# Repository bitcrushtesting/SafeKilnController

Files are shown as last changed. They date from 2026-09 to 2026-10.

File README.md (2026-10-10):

<!--
SPDX-FileCopyrightText: 2026 Bitcrush Testing
SPDX-License-Identifier: GPL-3.0-or-later
-->

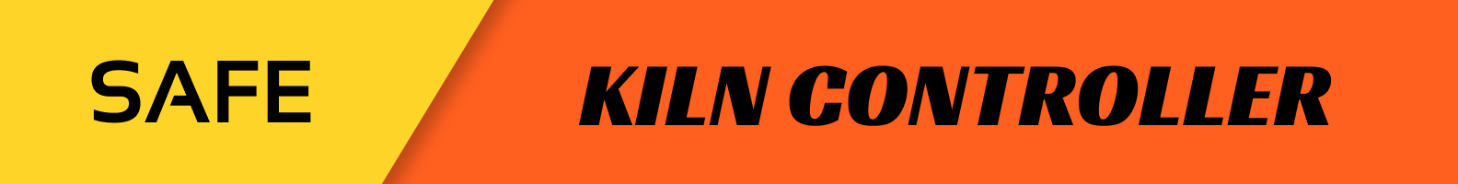
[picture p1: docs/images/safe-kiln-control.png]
Safe Kiln Controller


# Safe Kiln Controller








An open-source PID controller for electric ceramic and glass kilns, built on the
**ESP32-S3** with **ESP-IDF**.

- **Simple local display**: a 128×64 OLED showing current and target temperature at a glance, plus state, segment progress and rate of rise.
- **Web interface**: served by the device itself. Live dashboard, charts of the logged data, power and energy, and the firing programs the firmware carries. **Observation only**: nothing reachable over the network can start a firing, heat the kiln or change its configuration. Those are done at the kiln.
- **PID with automatic tuning**: relay (Åström–Hägglund) autotune on the real kiln; no manual gain hunting.
- **Firing profiles are compiled in**: the device ships with its curves and nothing edits them, not over the network and not at the kiln. That removes every authoring path and the attack surface each one carries, and it has a real cost: a curve of your own means building a firmware that carries it.
- **Safety first**: thermal runaway, thermocouple failure, shorted-SSR, over-temperature and door-interlock detection, with a safety supervisor that has sole authority over a heat-enable line that decays unless actively refreshed.
- **Current monitoring**: a current transformer turns relay and element failures from slow thermal inferences into fast electrical facts, with the thermal rules retained as an independent backstop.
- **Self-contained**: no SD card, no external database, no account, no filesystem. Logs live in a circular partition on internal flash and programs in a fixed-slot one, each built so a power cut cannot tear a record; web assets are embedded in the firmware. The device makes **one** outbound connection, a daily check for a firmware update that carries nothing about the device and can be turned off at the display.
- **Designed for testability**: all decision logic is hardware-free C++ that runs on a development host against a simulated kiln.

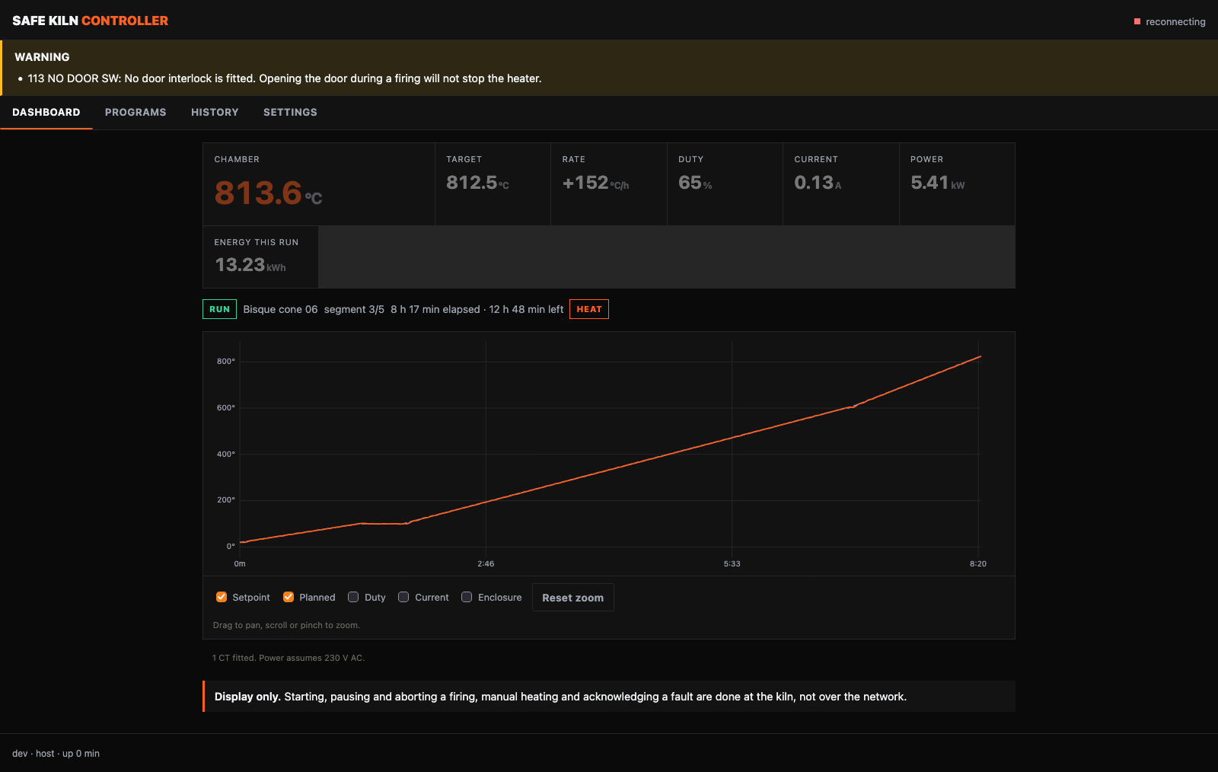
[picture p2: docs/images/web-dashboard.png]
The web dashboard during a bisque firing, showing 813.6 °C tracking an 812.5 °C setpoint at 152 °C/h in segment 3 of 5, with the logged curve and the preheat dwell visible


The dashboard mid-firing. Everything on it is read from the device: the `RUN`
and `HEAT` badges, the segment progress, the logged curve. There is no button
here that changes what the kiln is doing, because there is no route behind one
(`SWR-WEB-26`), which is why both notices at the foot of the page say so
plainly.

No kiln was involved. That is the development harness of
[`host/webhost`](firmware/controller/host/webhost) running the real firmware
logic against a simulated one, and it is two commands if you want to click
around yourself:

```sh
cmake -B build-webhost -S firmware/controller/host/webhost && cmake --build build-webhost
./build-webhost/webhost --accel 60 --fire "Bisque cone 06"   # then open http://127.0.0.1:8080
```

`--fire` exists because of the read-only interface: a firing cannot be started
from the browser, so the harness starts one of the built-in examples
(`SWR-PRG-09`) through the same call the local display makes.

## Status

**In development, and not ready to fire a kiln.** The control, safety, storage,
web and interface logic is written and tested. The hardware adapters are
written and **have never been run against a board**. Two things block a
release: the field update path is specified and unbuilt, and local control,
which is now the only control, has never been operated by a person.

433 host tests on the controller and 81 on the independent safety supervisor,
all green plain and under AddressSanitizer and UBSan. `clang-tidy` is clean on
host and target with no suppressions baseline, MC/DC over the supervisor's trip
logic is 100 % against an 80 % floor, the `esp32s3` image builds with zero
warnings at 246 kB (88 % of the OTA slot free), and QEMU boots that image and
fires it. The hardware configuration, which that one compiles out, builds at
908 kB with the browser interface gzipped into it and 56 % of the slot free.

The controller is C++20; the supervisor is C++17, which is the standard
MISRA C++:2023 is written against. What is done, what is not, and what blocks
a release is [`tasklist.md`](tasklist.md), which is kept current and is the
only place that count lives.

You can watch a complete firing, and break it in a dozen ways, without any
hardware at all, see [`docs/simulation.md`](docs/simulation.md):

```sh
tools/run-qemu.sh          # the firmware on an emulated ESP32-S3, kiln simulated
```

or run the logic tests directly:

```sh
cmake -B build-host -S firmware/controller/test/host && cmake --build build-host
ctest --test-dir build-host
```

CI runs eleven jobs: the layering and licence checks, both host suites plain
and under AddressSanitizer and UBSan, a coverage gate, `clang-tidy` on host and
on target, StrictDoc over the requirements, the `esp32s3` build with a size
report and a generated bill of materials, the supervisor suites with MC/DC, the
unit design document with documentation warnings as errors, and a QEMU job that
boots the real image and asserts that the simulated kiln passes 100 degC
without latching a fault. Tagging `v*` builds a release.

## Putting a unit into production

Two tools, in this order, because the order is not interchangeable:

```sh
tools/prod-data.py flash --serial SK1-2026-000042   # identity, a plain write
tools/secure-boot.py provision --key keys/prod.pem  # dry run; add --commit
```

The production data block first, while the device is still freely writable.
Then signing, flashing and lockdown.

The two differ in what they do by default, and the difference is the point.
`prod-data.py` writes unless told `--dry-run`, because its write is a plain
flash write that a reflash undoes. `secure-boot.py` does *nothing* unless told
`--commit`, because most of what it does cannot be undone at all. Both carry a
`--self-test` that needs neither a board nor ESP-IDF.

**`secure-boot.py` burns eFuses, and three of its four steps cannot be undone.**
It refuses to touch a board until its pre-flight passes, demands a differently
worded confirmation for each irreversible step, and sequences them so the device
is left bootable at every point. Read the header of
[`firmware/controller/sdkconfig.secure`](firmware/controller/sdkconfig.secure) before the first run;
the short version is that **losing the signing key means the unit can never run
new firmware again**, and that secure boot stops hostile code running but does
nothing about secrets being read off the flash (`SRR-05`).

### Releasing an update

A third tool, for the other end of the lifecycle. The device fetches one signed
static manifest per channel and verifies it against a key compiled into its own
firmware (`SWR-UPD-09` to `SWR-UPD-16`), and this builds that manifest:

```sh
tools/update-manifest.py keygen --key keys/manifest.pem          # once, then keep it offline
tools/update-manifest.py pubkey --key keys/manifest.pem \
    --header firmware/controller/main/update_pubkey.h            # the half that ships
tools/update-manifest.py sign   --key keys/manifest.pem \
    --image build-esp32s3/safekiln.bin --version 1.4.2 \
    --security --advisory advisories/2026-002.html
tools/update-manifest.py verify --manifest dist/update/stable.json \
    --pubkey keys/manifest.pub.pem --image build-esp32s3/safekiln.bin \
    --running-version 1.4.1
```

The **bill of materials** is generated rather than written
([`tools/sbom.py`](tools/sbom.py), `SWR-NFR-28`): the component list comes from
the build's own `project_description.json`, so it names what was actually
linked, and each licence is scanned from that component's own
`SPDX-License-Identifier` tags, with anything untagged reported as
`NOASSERTION` rather than given a plausible default. CycloneDX 1.6 by default,
SPDX 2.3 with `--format spdx`, both published with every release:

```sh
tools/sbom.py --build-dir firmware/controller/build \
    --image firmware/controller/build/safekiln.bin --format both --strict
```

It has to run where `$IDF_PATH` is, which in CI means inside the IDF container
rather than a step afterwards, because a licence cannot be scanned from a tree
that is not there. The question it exists to answer is "an advisory landed this
morning against mbedTLS 3.6.0, did we ship it", and that cannot be answered
after the fact.

**The manifest key is not the secure boot key, and the tool refuses to let it
be** (`SRR-12`). The secure boot key decides what a provisioned board will
*boot* and its digest is burnt into eFuses, so it can never be rotated; this one
decides what a board will be *offered* and is used on every release. `sign` also
refuses an image with no Secure Boot V2 signature, an image whose chip id is not
this target, a version carrying build metadata, and a security release with no
advisory, because each of those produces a manifest that every device must
reject after downloading it.

It deliberately does not burn `DIS_DOWNLOAD_MODE`. Serial download is
`SWR-UPD-14`'s recovery path, for a unit whose update service is unreachable,
whose new image will not confirm itself, or which has to be downgraded; closing
it as well would make such a unit permanently unfixable.

| Document | Contents |
|---|---|
| [`docs/v-model-process.md`](docs/v-model-process.md) | The development process: the V-model levels, which document holds each, the relations between them, and an honest record of which levels exist and which do not. |
| [`docs/01_user_req.sdoc`](docs/01_user_req.sdoc) | User requirements: the target markets (the European Union), the regulatory framework that follows from them with instrument numbers and editions, the user needs with their acceptance criteria, and the project constraints. |
| [`docs/02_system_req.sdoc`](docs/02_system_req.sdoc) | System requirements: the hardware interface, the four safety requirements that hardware discharges, and the assumptions about the environment the system is placed in. |
| [`docs/03_software_req.sdoc`](docs/03_software_req.sdoc) | Software requirements: the functional, safety, non-functional and testability requirements, each with an identifier and a verification method. |
| [`docs/04_software_arch.sdoc`](docs/04_software_arch.sdoc) | Software architecture: the 22 decisions the design rests on, each with the requirement that drove it and the cost it carries. |
| [`docs/safety.sdoc`](docs/safety.sdoc) | Hazards, safety goals and residual risks, each with an identifier, and the chain between them as checked relations: which hazards a goal mitigates, which requirements realise it, and which risk its layers leave. |
| [`docs/safety.md`](docs/safety.md) | Safety concept: the system boundary, the layered protection concept and the independence claimed between layers, detection coverage and timing, the reaction and recovery sequence, and the obligations on the installer and on anyone changing the design. |
| [`docs/security.sdoc`](docs/security.sdoc) | Assets, adversaries, threats, security goals, residual risks and open questions, each with an identifier, and the chain between them as checked relations: which asset a threat is aimed at, which safety hazard it reaches, which goal answers it, and what each goal's implementation status actually is. |
| [`docs/security.md`](docs/security.md) | Security concept: scope, the attack surface and trust boundaries, the physical boundary and why the supervisor's debug port is deliberately open, the update path and why it points outwards, why a security compromise here is a safety event, what the implementation already gets right, the obligations on the owner and on whoever implements the HTTP transport, the verification status, and an inventory of what the Cyber Resilience Act still requires. |
| [`SECURITY.md`](SECURITY.md) | The security policy: where to report a vulnerability and what happens then, the single point of contact and the reporting obligations behind it, the supported versions and the support period, how a fix reaches a device, and what is already documented as a residual risk so a report need not restate it. |
| [`docs/architecture.md`](docs/architecture.md) | Architecture prose: component decomposition, task and timing design, control and safety algorithms, persistence and flash-endurance design, REST API, and the build and test architecture. |
| [`docs/test-concept.md`](docs/test-concept.md) | How the product is verified: unit, integration, system and hardware-in-the-loop, what each level can and cannot prove, the HIL fixture design, and an honest status against every testability requirement. |
| [`docs/safety-supervisor.md`](docs/safety-supervisor.md) | The independent safety supervisor (`SWA-22`): a second microcontroller holding the absolute over-temperature, thermocouple-fault and lid trips, what moves and what stays, the link, the failure modes, and the questions still open. |
| [`docs/coding-standard.md`](docs/coding-standard.md) | The coding standard: which safety standards actually reach the source code and what each asks for, the language subset and the flags that enforce it, why the supervisor contains no floating point, how a deviation is recorded, and what is not met yet. |
| [`docs/simulation.md`](docs/simulation.md) | Running the firmware against a simulated kiln, on the host and under QEMU, including fault injection. |
| [`tasklist.md`](tasklist.md) | Outstanding work, by priority. |

Start with [`docs/03_software_req.sdoc`](docs/03_software_req.sdoc); the architecture
document cites it throughout.

## Repository layout

```
docs/                  requirements, architecture, safety and security
firmware/controller/   the ESP-IDF application
firmware/supervisor/   the independent safety supervisor, STM32G031
web/                   the browser interface, served by the device
tools/                 release, provisioning, analysis and document generation
fixture/               the bed-of-nails test fixture
hardware/              schematic, PCB, pin map
housing/               enclosure
```

## Scope

Safe Kiln Controller supports **single-phase kilns only**. A three-phase kiln can be
monitored on one representative phase, but a fault confined to one of the other
two would be caught only by the thermal rules, slowly, and the power and energy
figures would cover a third of the load. Neither is a safe basis for firing a
three-phase kiln, so it is out of scope rather than partially supported.

## Hardware at a glance

| Part | Choice |
|---|---|
| MCU | ESP32-S3, ≥ 8 MB flash, no PSRAM required |
| Temperature | MAX31856 front ends, type-K. The controller reads chamber and enclosure; the **supervisor reads its own chamber couples on its own SPI buses**, so neither processor depends on the other for a temperature |
| Display | 128×64 monochrome OLED, I²C |
| Input | Rotary encoder with push button |
| Output | Zero-cross SSR in series with a safety contactor |
| Supply | **Single phase only.** One current transformer on the heater conductor |
| Door interlock | Optional normally-closed switch, stops the heater immediately when the door opens |
| Connectivity | WiFi station only. **No access point:** the network is selected and its passphrase typed at the display, so setting it up needs somebody at the kiln. Reachable at `kiln.local` over mDNS, and by IP, which the display shows |

Details and rationale are in
[requirements §6](docs/03_software_req.sdoc).

## Credit

Functionally inspired by [**PIDKiln**](https://github.com/Saur0o0n/PIDKiln) by
Adrian Siemieniak, which showed that a low-cost ESP32 can run a real kiln well.
Safe Kiln Controller borrows its ideas, segment-based programs, dual local/web control,
on-device storage, a redundant SSR + contactor output stage, and rebuilds them
on ESP-IDF with a host-testable core and automatic PID tuning. No PIDKiln source
code is used

## Safety

Safe Kiln Controller is **not** a safety-certified device. A kiln is a multi-kilowatt mains
heater reaching temperatures at which its own wiring and the surrounding building
are at risk.

Mains wiring must be carried out by a competent person in accordance with local regulation.

The hazards, the layered protection concept and the risk that remains are
set out in [`docs/safety.md`](docs/safety.md); the requirements it derives from
are [requirements §5](docs/03_software_req.sdoc).

Safe Kiln Controller is designed for a **trusted local network** and must not be exposed
to the internet. The threat model, the controls and what is still only specified are in [`docs/security.md`](docs/security.md).

## License

GPL-3.0-or-later. See [`LICENSE`](LICENSE).

    Copyright (C) 2026 Bitcrush Testing

    This program is free software: you can redistribute it and/or modify it
    under the terms of the GNU General Public License as published by the Free
    Software Foundation, either version 3 of the License, or (at your option)
    any later version.

    This program is distributed in the hope that it will be useful, but WITHOUT
    ANY WARRANTY; without even the implied warranty of MERCHANTABILITY or
    FITNESS FOR A PARTICULAR PURPOSE.  See the GNU General Public License for
    more details.

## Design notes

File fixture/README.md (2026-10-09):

<!--
SPDX-FileCopyrightText: 2026 Bitcrush Testing
SPDX-License-Identifier: GPL-3.0-or-later
-->

# Bed-of-nails fixture

The hardware-in-the-loop fixture for the controller board, built from the board
itself by [pinside](https://github.com/bitcrushtesting/pinside). This is the
fixture `docs/test-concept.md` wants and that the M4 and M4b milestones need:
`safety.md` §10 still lists the central claim of the design, that the contactor
releases when the safety task stops, as **not yet performed**, and nothing in
this repository can perform it without a jig.

## What is here

| | |
|---|---|
| `kilncontrol-fixture.json` | the fixture definition. **This is the source**; everything else is generated from it |
| `pinside-baseline.json` | findings on the DUT that have been looked at and accepted, with the reason for each |
| `board/` | a KiCad project for the fixture board, generated |
| `firmware/` | firmware for the fixture's controller, generated |

`board/` and `firmware/` are generated verbatim and are regenerated, not edited.
pinside derives footprint UUIDs from the config rather than randomising them, so
an unchanged config produces a byte-identical project and the diff of a real
change is only the change.

## Regenerating

```sh
pip install pinside                       # or run from a checkout, see its README
pinside check    hardware/safekiln.kicad_pcb --baseline fixture/pinside-baseline.json
pinside project  fixture/kilncontrol-fixture.json --out fixture/board
pinside generate fixture/kilncontrol-fixture.json --out fixture/firmware
bash fixture/firmware/test/run.sh         # 128 host checks, no hardware needed
```

`project` needs KiCad installed, because a schematic embeds a copy of every
symbol it places. `check` and `generate` do not. The board file is only ever
read; pinside never writes KiCad sources.

## Two decisions worth knowing

**The probe is a Mill-Max 0906, not the default 0985.** With the 0985's 2.54 mm
minimum pitch, eight probe pairs on this board collide: TP2-TP3, TP6-TP9,
TP7-TP8, TP15-TP16, TP19-TP20, TP20-TP22, TP21-TP34 and TP32-TP36 all sit at
exactly 2.50 mm, because the test points are on a 2.5 mm grid and the receptacle
body is wider than that. The 0906's 1.91 mm pitch clears all eight, and its
lower 0.55 N force halves the plate load as a side effect. Its dimensions are
pinside's reading of the Mill-Max catalogue and **nobody has checked them
against a supplier drawing**; do that before ordering.

**The fixture carries the RP2350 itself rather than a Pico 2 module.** 28 test
points need more channels than a Pico 2's 26 header GPIO, and the first attempt
failed on exactly that: `COIL_PERMIT` and `SUPERVISOR_RESET` had nowhere to go,
with one GPIO spare. Those two are the permit line and the supervisor's reset,
which are the whole point of a safety fixture, so the carrier is `bare` with an
`rp2350b` (48 GPIO).

## What still blocks building it

**The board has no mounting holes, and that is two problems rather than one.**
`PS050` reports it as "the DUT can pivot or rock and contact becomes
intermittent", which is the mechanical half. The other half is quieter: on a
pinside fixture **the ground return goes through the grounded mounting holes**,
which is why `GND` is not a channel and why only 27 of the 28 test points get a
probe. pinside's own example board has its mounting holes on the `GND` net. With
no holes at all, the fixture's ground pour connects to the DUT through nothing,
and `PS031`, "only one ground test point", is the same problem seen from the
other side.

So before a fixture can be ordered the controller board needs **at least three
plated mounting holes on the GND net**, positioned so the probes fall inside
their span (`PS052` watches for that). Both findings are deliberately left out
of the baseline so they keep failing until that happens.

**Two analogue channels are placed but cannot be used.** `TC1_P` and `TC1_N` are
the thermocouple's millivolt inputs. The probes are placed so the pads are
reachable, and both are configured as observed inputs that the fixture **never
drives**: a GPIO asserting 3V3 into a thermocouple input can damage the front
end. Injecting a temperature, which is what a HIL suite actually wants, needs a
calibrated millivolt source the fixture does not have. `CURR_SENSE` is in the
same position and should become an ADC channel once the conditioning scale is
taken from the schematic; it is left as an observed input rather than having a
scale invented for it.

## The directions were reviewed, and the schematic is the authority

`pinside init` drafts a config and says to treat it as a draft. It defaulted
almost every signal to `open_drain` with `active_low`, which is a safe default
because `released` means not driving, but it is a default rather than an
analysis. The directions here were set by hand from the net names:

- **13 observed inputs**, every signal the DUT drives: `SSR1`, `HEAT_EN`,
  `PUMP_NODE`, `HEAT_EN_DC`, `COIL_DRV`, `COIL_PERMIT`, `ALARM`, `TC1_DRDY`,
  `TC1_FAULT`, `TC1_CS`, plus the three analogue ones above. A fixture that
  drove any of these would contend with the board.
- **6 driven**, the signals the DUT reads: `ENC_A`, `ENC_B`, `ENC_BTN`,
  `ESP32_EN`, `ESP32_IO0`, `SUPERVISOR_RESET`. Open-drain and active-low suits
  all six: each sits on a pull-up, and released means the fixture is holding the
  board in no particular state.

`TC1_CS` deserves its own note. The config declares an SPI peripheral in master
role, so the fixture *can* drive that bus, but chip select is left as an input
because the controller drives it in normal operation. Mastering the bus means
holding the DUT in reset through `ESP32_EN` first, and that interlock is not
configured here: it is a deliberate act, not a default.

These are a reading of the net names and of the firmware, not of the schematic.
**Check them against the schematic before power is applied to a real board**,
because the failure mode of a wrong direction is two drivers fighting.

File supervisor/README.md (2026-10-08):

<!--
SPDX-FileCopyrightText: 2026 Bitcrush Testing
SPDX-License-Identifier: GPL-3.0-or-later
-->

# The independent safety supervisor

Firmware for the second microcontroller of [`AD-22`](../docs/architecture.sdoc).
It reads the chamber thermocouple, the front end's fault output and the lid
switch, holds one series element in the contactor coil, and reports to the
ESP32 over a one-way serial link. It takes no instruction from anything.

The design, the failure analysis and the open questions are in
[`docs/safety-supervisor.md`](../docs/safety-supervisor.md).

## The part: STM32G031K8T6

| | |
|---|---|
| Part | STM32G031K8T6 |
| Core | Cortex-M0+ at 16 MHz from HSI16, no crystal |
| Memory | 64 KB flash (3.5 KB used), 8 KB RAM |
| Package | LQFP32, 0.8 mm pitch |
| Uses | SPI1, USART2, IWDG, 8 GPIO |

### Pins

Taken from ST's own data: the pinout and alternate functions from CubeMX's MCU
database for this part, the register and bit positions from the CMSIS-SVD.
Neither is a build-time fetch, both ship with ST's tools.

| Pin | Pos | Function | Mode |
|---|---|---|---|
| `PA0` | 7 | clear button | input, pull-up |
| `PA2` | 9 | UART TX to the ESP32 | AF1, `USART2_TX` |
| `PA3` | 10 | MAX31856 `~FAULT` | input, pull-up |
| `PA4` | 11 | MAX31856 `~CS` | output, idle high |
| `PA5` | 12 | SPI1 `SCK` | AF0 |
| `PA6` | 13 | SPI1 `MISO` | AF0 |
| `PA7` | 14 | SPI1 `MOSI` | AF0 |
| `PA8` | 18 | coil permit | output, low opens the coil |
| `PA13` | 24 | `SWDIO` | reserved |
| `PA14` | 25 | `SWCLK` | reserved |
| `PF2` | 6 | `NRST` | |

Three properties of this assignment are deliberate and should survive any
change to it.

**Everything is on port A.** `startup.cpp` drives the permit line low before
`.data` is copied, and enables exactly one GPIO clock to do it. A function
moved to port B would be driven before its port had a clock.

**`PA9` to `PA12` are avoided entirely.** On this package `PA11`/`PA12` can be
remapped to act as `PA9`/`PA10` through `SYSCFG_CFGR1`, and positions 19 and 21
are listed as NC-or-`PA9`/`PA10` depending on bonding. A supervisor should not
depend on a remap bit being right.

**The UART's receive pin is never configured.** `USART2_RX` would be `PA3`, and
`PA3` is the `~FAULT` input instead, so the simplex link is unwired rather than
merely unused. `RE` is left clear in `CR1` for the same reason.

`PA5`/`PA6`/`PA7` are adjacent and all AF0, putting the whole SPI bus on three
neighbouring pins beside the chip select. Free for later: `PA1`, `PA15`,
`PB0`–`PB9`, `PC6`, `PC14`, `PC15`.

One requirement this places on the hardware: the permit line is active high and
every GPIO is high-impedance between reset and the first instruction, so the
series element must be held off by an **external pull-down**, not by this pin.
Without it there is a window at every reset where the element's state is
whatever the board leaks to.

Why this one:

- **The `IWDG` is clocked from the LSI, not the system clock.** This is the
  property that decided the family. A supervisor whose watchdog stops when its
  clock stops is not a supervisor, and on the G0 the independent watchdog runs
  from its own oscillator and cannot be disabled in software once started.
- **LQFP32 rather than QFN.** Hand-solderable, reworkable, and every pin can be
  probed, which matters for a part whose whole argument is that it can be
  verified independently. `HR-19` already requires top-side test points for the
  same reason.
- **64 KB of flash against a firmware that currently uses 3.5 KB.** The
  headroom is not for features. It is for self-tests, and for the fact that a
  part running at 5 % of its flash will still build in ten years.
- Cheap, long-lived and widely stocked, which for a safety part matters more
  than the last few cents. The G0 line also has ST functional-safety material
  available, which is worth having if a claim is ever made formally.

It needs **SWD brought out to test points**, not optional: the independence
argument rests on this firmware being reviewable and flashable without going
through the ESP32.

## Layout

```
supervisor/
  protocol/     the wire format, shared with the ESP32 adapter
  core/         the trip logic: the whole safety function, host-tested
  board/        STM32G031 registers, startup, linker script, pin map
  src/main.cpp  composition root: bring-up and the 10 Hz loop
  test/host/    24 tests, no ARM toolchain needed
```

The split is the one [`AD-01`](../docs/architecture.sdoc) makes on the other
side of the link, for the same reason: everything that *decides* is
platform-free and exercised on a development host, and what needs the silicon
is thin enough to read.

`core/` shares no code with the ESP32's safety rules. That is the point of
`AD-22`; any resemblance is a resemblance and not reuse. The one file both
projects include is `protocol/include/sup_proto.h`, which is declarative, and
the host test harness, which is macros.

## Building

Host tests, which is where the safety logic is verified:

```sh
cmake -B build-sup -S supervisor/test/host
cmake --build build-sup -j
ctest --test-dir build-sup --output-on-failure
```

Target firmware. The compiler ships with STM32CubeCLT, so nothing is fetched at
build time (`CON-04`):

```sh
cmake -B build-sup-target -S supervisor \
      -DCMAKE_TOOLCHAIN_FILE=$PWD/supervisor/arm-none-eabi.cmake
cmake --build build-sup-target -j
```

`board/stm32g031.h` is generated from ST's own CMSIS-SVD by
[`tools/gen-stm32g031-header.py`](../tools/gen-stm32g031-header.py). Regenerate
it rather than editing it: the reason it is generated is that then no address in
it is anybody's recollection.

## What is done, and what is not

**Done and tested:** the trip logic (14 tests), the wire format (10 tests) and
the MAX31856 register decode (9 tests). Between them that is the entire safety
function, the entire interface and the arithmetic that turns six register bytes
into a temperature, and none of it needs hardware to exercise. MC/DC is measured
over all three and is at 100 % against an 80 % floor (`tools/mcdc.sh`).

The decode is in `sup_core` rather than beside the SPI code on purpose. Two's
complement reassembled across three registers and shifted back with a
sign-extending shift is not something to get right by inspection: a logical
shift there reads -1 degC as +524287, which is above the backstop, so a cold
kiln would trip. Its test vectors were produced by encoding known temperatures
from the datasheet's register layout, not by recording what the decoder
returned.

**Written but never run on silicon:** the peripheral bring-up in `main.cpp` and
the alternate-function numbers in `board/pins.h`. The register addresses are
ST's, but the AF mappings live in the datasheet rather than the SVD and are
marked `(confirm)` where they are assumed. What is unverified is now the
*transport* rather than the logic: the SPI configuration, the chip-select
timing, the SysTick period and the USART bring-up. Each is a small separate
function so it can be brought up and checked one at a time on a bench.

The start-up self-test is real rather than a stub returning "not configured". It
writes MASK, CR1 and CR0, reads CR1 back to tell a configured part from a dead
bus, and then waits for a conversion to actually complete before the trip logic
is allowed to run at all. That last step is not ceremony: before the first
conversion the temperature registers read zero, and zero decodes as a
plausible, in-range, fault-free 0 degC. It is the one reading that would permit
heat on a kiln whose temperature is not yet known.

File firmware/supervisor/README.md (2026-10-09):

<!--
SPDX-FileCopyrightText: 2026 Bitcrush Testing
SPDX-License-Identifier: GPL-3.0-or-later
-->

# The independent safety supervisor

Firmware for the second microcontroller of [`SWA-22`](../docs/04_software_arch.sdoc).
It reads the chamber thermocouple, the front end's fault output and the lid
switch, holds one series element in the contactor coil, and reports to the
ESP32 over a one-way serial link. It takes no instruction from anything.

The design, the failure analysis and the open questions are in
[`docs/safety-supervisor.md`](../docs/safety-supervisor.md).

## The part: STM32G031K8T6

| | |
|---|---|
| Part | STM32G031K8T6 |
| Core | Cortex-M0+ at 16 MHz from HSI16, no crystal |
| Memory | 64 KB flash (3.4 KB used), 8 KB RAM |
| Package | LQFP32, 0.8 mm pitch |
| Uses | SPI1, USART2, IWDG, 8 GPIO |

### Pins

Taken from ST's own data: the pinout and alternate functions from CubeMX's MCU
database for this part, the register and bit positions from the CMSIS-SVD.
Neither is a build-time fetch, both ship with ST's tools.

| Pin | Pos | Function | Mode |
|---|---|---|---|
| `PA0` | 7 | clear button | input, pull-up |
| `PA2` | 9 | UART TX to the ESP32 | AF1, `USART2_TX` |
| `PA3` | 10 | MAX31856 `~FAULT` | input, pull-up |
| `PA4` | 11 | MAX31856 `~CS` | output, idle high |
| `PA5` | 12 | SPI1 `SCK` | AF0 |
| `PA6` | 13 | SPI1 `MISO` | AF0 |
| `PA7` | 14 | SPI1 `MOSI` | AF0 |
| `PA8` | 18 | coil permit | output, low opens the coil |
| `PA13` | 24 | `SWDIO` | reserved |
| `PA14` | 25 | `SWCLK` | reserved |
| `PF2` | 6 | `NRST` | |

Three properties of this assignment are deliberate and should survive any
change to it.

**Everything is on port A.** `startup.cpp` drives the permit line low before
`.data` is copied, and enables exactly one GPIO clock to do it. A function
moved to port B would be driven before its port had a clock.

**`PA9` to `PA12` are avoided entirely.** On this package `PA11`/`PA12` can be
remapped to act as `PA9`/`PA10` through `SYSCFG_CFGR1`, and positions 19 and 21
are listed as NC-or-`PA9`/`PA10` depending on bonding. A supervisor should not
depend on a remap bit being right.

**The UART's receive pin is never configured.** `USART2_RX` would be `PA3`, and
`PA3` is the `~FAULT` input instead, so the simplex link is unwired rather than
merely unused. `RE` is left clear in `CR1` for the same reason.

`PA5`/`PA6`/`PA7` are adjacent and all AF0, putting the whole SPI bus on three
neighbouring pins beside the chip select. Free for later: `PA1`, `PA15`,
`PB0`–`PB9`, `PC6`, `PC14`, `PC15`.

One requirement this places on the hardware: the permit line is active high and
every GPIO is high-impedance between reset and the first instruction, so the
series element must be held off by an **external pull-down**, not by this pin.
Without it there is a window at every reset where the element's state is
whatever the board leaks to.

Why this one:

- **The `IWDG` is clocked from the LSI, not the system clock.** This is the
  property that decided the family. A supervisor whose watchdog stops when its
  clock stops is not a supervisor, and on the G0 the independent watchdog runs
  from its own oscillator and cannot be disabled in software once started.
- **LQFP32 rather than QFN.** Hand-solderable, reworkable, and every pin can be
  probed, which matters for a part whose whole argument is that it can be
  verified independently. `SYS-HW-19` already requires top-side test points for the
  same reason.
- **64 KB of flash against a firmware that currently uses 3.4 KB.** The
  headroom is not for features. It is for self-tests, and for the fact that a
  part running at 5 % of its flash will still build in ten years.
- Cheap, long-lived and widely stocked, which for a safety part matters more
  than the last few cents. The G0 line also has ST functional-safety material
  available, which is worth having if a claim is ever made formally.

It needs **SWD brought out to test points**, not optional: the independence
argument rests on this firmware being reviewable and flashable without going
through the ESP32.

## Layout

```
firmware/supervisor/
  protocol/     the wire format, shared with the ESP32 adapter
  core/         the trip logic: the whole safety function, host-tested
  board/        STM32G031 registers, startup, linker script, pin map
  src/main.cpp  composition root: bring-up and the 10 Hz loop
  test/host/    24 tests, no ARM toolchain needed
```

The split is the one [`SWA-01`](../docs/04_software_arch.sdoc) makes on the other
side of the link, for the same reason: everything that *decides* is
platform-free and exercised on a development host, and what needs the silicon
is thin enough to read.

`core/` shares no code with the ESP32's safety rules. That is the point of
`SWA-22`; any resemblance is a resemblance and not reuse. The one file both
projects include is `protocol/include/sup_proto.h`, which is declarative, and
the host test harness, which is macros.

## Building

Host tests, which is where the safety logic is verified:

```sh
cmake -B build-sup -S firmware/supervisor/test/host
cmake --build build-sup -j
ctest --test-dir build-sup --output-on-failure
```

Target firmware. The compiler ships with STM32CubeCLT, so nothing is fetched at
build time (`UR-CON-04`):

```sh
cmake -B build-sup-target -S supervisor \
      -DCMAKE_TOOLCHAIN_FILE=$PWD/firmware/supervisor/arm-none-eabi.cmake
cmake --build build-sup-target -j
```

`board/stm32g031.h` is generated from ST's own CMSIS-SVD by
[`tools/gen-stm32g031-header.py`](../tools/gen-stm32g031-header.py). Regenerate
it rather than editing it: the reason it is generated is that then no address in
it is anybody's recollection.

## What is done, and what is not

**Done and tested:** the trip logic, the wire format, the MAX31856 register
decode and the self-diagnostics: 81 host tests over four suites, with MC/DC at
100 % over all of it against an 80 % floor. `clang-tidy` reaches this component
too, as of the tidy.sh widening: core, protocol and the suites from the host
compile database, and `src/main.cpp` and `board/startup.cpp` against a
synthesised bare-metal one, so no file here is outside the project's gates. The
standard it is held to is [`docs/coding-standard.md`](../docs/coding-standard.md).

**No floating point.** The temperatures are fixed point throughout: 1/128 degC
inside, the MAX31856's own LSB, and tenths of a degree on the wire. On a
Cortex-M0+ a float compare is a libgcc soft-float call, so the previous version
linked 2.7 kB of helpers and newlib's `lroundf` into a safety function, and
every comparison needed a NaN case. The image is 3 488 bytes of text now against
6 736 before. See [`docs/coding-standard.md` §5](../docs/coding-standard.md).

One coverage gap is worth naming rather than leaving to be found. The two
failure returns inside the RAM pattern test are unreachable from a host test,
because host RAM cannot be made to fail on demand. That is why the comparison
they depend on, `sup_ram_word_ok`, is a separate function with its own tests for
a bit stuck high, a bit stuck low and both polarities of a wrong word. The loop
around it is four lines; the judgement in it is tested. Between them that is the entire safety
function, the entire interface and the arithmetic that turns six register bytes
into a temperature, and none of it needs hardware to exercise. MC/DC is measured
over all three and is at 100 % against an 80 % floor (`tools/mcdc.sh`).

The decode is in `sup_core` rather than beside the SPI code on purpose. Two's
complement reassembled across three registers and shifted back with a
sign-extending shift is not something to get right by inspection: a logical
shift there reads -1 degC as +524287, which is above the backstop, so a cold
kiln would trip. Its test vectors were produced by encoding known temperatures
from the datasheet's register layout, not by recording what the decoder
returned.

**Written but never run on silicon:** the peripheral bring-up in `main.cpp` and
the alternate-function numbers in `board/pins.h`. The register addresses are
ST's, but the AF mappings live in the datasheet rather than the SVD and are
marked `(confirm)` where they are assumed. What is unverified is now the
*transport* rather than the logic: the SPI configuration, the chip-select
timing, the SysTick period and the USART bring-up. Each is a small separate
function so it can be brought up and checked one at a time on a bench.

### Self-diagnostics

Three measures, added because an assessment against EN IEC 60730-1 Annex H or
EN ISO 13849-1 asks for them and a single-channel supervisor can only claim
diagnostic coverage for what it actually observes.

**Clock integrity** (`sup_clock_ok`). The clock switch status must agree with the
selection, HSI must be ready, and the PLL must be off. Every check is phrased as
an invariant that holds whatever the `SWS` encoding turns out to be, because this
part's SVD carries no enumerated values for it and its `RCC_CR` reset value
disagrees with the reference manual. Guessing a bit pattern in a safety check is
not worth the brevity.

**Program memory integrity** (`sup_flash_ok`). CRC-32 over the whole image from
the vector table to `_sup_crc_region_end`, compared against a digest stamped into
`.sup_crc` after linking by `tools/sup-crc.py`. The digest sits immediately after
the region because a digest cannot cover itself, and the tool checks that
invariant rather than trusting the linker script. An **unstamped** image fails:
`SUP_CRC_UNPROGRAMMED` is a failure, not "no expectation", because an image that
reached a board without being stamped is exactly the one whose integrity is
unknown. The stamp is a build step so it cannot be forgotten.

**Working memory** (`SWR-SAF-33`). A pattern test that drives every bit of every
tested word to both states, plus an **address-dependent** pattern. The second one
is required rather than decorative: two words that alias because an address line
is stuck pass every uniform pattern, since both hold the same value and both read
back what was written. They fail only when asked to hold two different values at
once.

The whole free region is tested once before heat can be permitted, and then
walked 64 bytes a cycle for ever. The region walked is the memory between the
stack guard and the current stack pointer, which nothing is using, so no save and
restore is needed and it is exactly the memory the stack will grow into. When the
stack has grown too close to leave a safe window, the test declines that cycle
rather than reporting a failure: a nuisance trip is worse than a missed cycle of
a test that runs ten times a second.

**Stack overflow** (`SWR-SAF-34`). 256 words of guard below the stack, filled at
start-up and checked in full every cycle. Every word, not a sample, because the
stack arrives at the top of the region and a sampled check would miss the shallow
overflow, which is the one still worth catching.

**Program sequence** (`SWR-SAF-35`). The four stages of the cycle announce
themselves, and at the end the supervisor checks that each ran exactly once and in
order. This catches what a watchdog cannot: a cycle that finished on time having
skipped the stage that drives the permit line, or one a corrupted branch entered
halfway through. Both produce a cycle of the right duration doing the wrong work.
The verdict necessarily lands in the following cycle, since a sequence can only be
judged once it has finished, which costs 100 ms against `SWR-NFR-04`'s 500 ms.

**A failed diagnostic is not clearable** (`SWR-SAF-36`). Any diagnostic failure,
at start-up or running, revokes the self-test rather than merely tripping. That
makes it unclearable by the local button and keeps the permit false for good,
because the permit is conjunctive on the self-test. The distinction is deliberate:
the button exists so an operator can acknowledge a condition they can see and have
dealt with, and a supervisor whose memory, stack, clock, image or program sequence
has failed is not in that category. A button that returned it to service would be
overriding the diagnostic rather than the fault.

The diagnostics reach the trip logic through `diag_ok` on the input snapshot,
which is **positive logic** so that a zero-initialised input withholds heat. That
is the convention `chamber_valid` already uses, and for the same reason: the safe
state has to be the one you get by forgetting to set a field. One test does
nothing but check that.

**A windowed watchdog**, which is the clock cross-check and is easy to mistake
for an ordinary watchdog. The IWDG counts from the LSI, an oscillator the system
clock cannot influence. Feeding late resets, as before. Feeding **early**, while
the counter is still above `IWDG_WINDOW`, now also resets, so the 100 ms cycle is
measured against an independent oscillator from both sides. That makes three
previously silent failures loud:

| failure | before | now |
|---|---|---|
| system clock running fast | undetected | early feed resets |
| LSI stopped | **watchdog never fires** | counter never leaves the reload, first feed resets |
| system clock slow, or loop hung | timeout | timeout, unchanged |

The LSI one matters most: a dead LSI meant a watchdog that could never fire, so
the protection the design leans on would have been absent with no indication.

What it does **not** catch is small drift, and the limit is the LSI's own
tolerance rather than a design choice. At 32 kHz ±10 % a 100 ms cycle is 45 to 55
ticks, putting the counter at 120 to 130 when the feed arrives, so the window has
to sit above that or a healthy board resets itself. 140 leaves ten ticks for loop
jitter and detects a system clock roughly 1.3× fast or worse. That is
gross-failure detection. A 2 % drift is not caught and does not need to be: it
does not threaten the safety function, whereas a nuisance reset of the supervisor
would be worse than the fault.

Every feed in the firmware sits immediately after `wait_for_cycle_end()`, which
is the one place a full cycle is known to have elapsed. With a window, that is no
longer a style preference.

The start-up self-test is real rather than a stub returning "not configured". It
writes MASK, CR1 and CR0, reads CR1 back to tell a configured part from a dead
bus, and then waits for a conversion to actually complete before the trip logic
is allowed to run at all. That last step is not ceremony: before the first
conversion the temperature registers read zero, and zero decodes as a
plausible, in-range, fault-free 0 degC. It is the one reading that would permit
heat on a kiln whose temperature is not yet known.

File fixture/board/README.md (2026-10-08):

# kilncontrol-fixture fixture board

Generated by pinside 0.2.0 on 2026-10-08 from
`kilncontrol-fixture.json`.

**Regenerating overwrites this project.** Change the config, not the board, except for routing,
which pinside does not generate and will not overwrite once you have done it. If you intend to
route it, copy the project somewhere else first.

## What is already right

The part that has to be exact is the placement, and it is not laid out here at all: it is read
out of the DUT and carried through the fixture transform:

- **27 probes**, each at its DUT test point's own coordinates.
- **The outline and mounting holes**, taken from the DUT, so the two boards bolt together.
- Frame: origin `outline`, mirror `x`.
- Board: 100 x 70 mm.

## What is left to you

- **Routing.** A ratsnest and an accurate drill plan are the useful part; guessing trace paths is
  not. Autoroute it or draw it.
- **Placing the controller and any connectors.**
- **Filling the zones.** A GND pour is already drawn on both copper layers, held
  0.5 mm back from the edge. KiCad fills it on `Edit > Fill All Zones`.

## The probe

Mill-Max 0906 receptacle with a 0850 series spring pin, 1.91 mm pitch

| | |
|---|---|
| Receptacle | `0906-0-15-20-76-14-11-0` |
| Spring pin | `0850-0-15-20-82-14-11-0` |
| Hole | 1.02 mm |
| Pad | 1.7 mm |
| Minimum pitch | 1.91 mm |
| Travel | 1.8 mm |
| Force | 0.55 N per pin at mid-travel |
| Mounting | press-fit |
| Source | Mill-Max catalogue, 0906 receptacle and 0850 spring pin series |
| Checked against the drawing | **no** |

These dimensions were transcribed from a catalogue and nobody has checked them against the supplier's own drawing. **Do that before you order**: series get revised, and a receptacle 0.1 mm fatter than this expects is a board that has to be redrilled.

The footprint is generated into `pinside.pretty/`, and `fp-lib-table` already points at it.

## Closing force

27 probes at 0.55 N each is **15 N** (1.5 kgf) at full travel.

A hand clamp or a couple of thumbscrews will close this. The load is small enough that the plate's own stiffness is what decides whether contact is even.

The DUT has no mounting holes, so there is nowhere to put a standoff. The plate has to be located some other way, and whatever locates it carries all of this.

## The controller

**Bare rp2350b on the fixture board.** The schematic does not draw it: add the MCU, its supply, crystal and USB, then wire the `FIX_*` nets.

## Mirroring

`mirror = x`. A fixture whose probes point up takes the DUT face-down,
which mirrors X. Get this wrong and the board is a perfect mirror image of the one you need, so
before ordering, print `pinside check <dut> -f svg` at 1:1 and lay the real board on it.

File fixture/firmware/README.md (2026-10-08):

# kilncontrol-fixture firmware

Bed-of-nails fixture for the Safe Kiln Controller, drafted by `pinside init` and then reviewed by hand. Directions are set from the schematic's net names: every signal the DUT drives is an observed input, and only the six the DUT reads are driven. The schematic is the authority; see fixture/README.md for what is still open.

Generated by pinside 0.2.0 from `kilncontrol-fixture.json`, checked against
`/Users/bernhardtrinnes/Developer/Bitcrush/kilncontrol/hardware/kilncontrol.kicad_pcb`.

**Config hash `3db150410419`.** `fixture.info` reports it. If it does not match the config you are
holding, the board in front of you was built from something else.

## Build

```bash
cmake -B build -DPICO_SDK_PATH=/path/to/pico-sdk
cmake --build build
```

Hold BOOTSEL, plug the fixture in, and copy `build/kilncontrol_fixture.uf2` onto it.

## Test, without hardware

```bash
test/run.sh
```

Builds the protocol core and the generated channel tables against a mock HAL, with the address
and undefined-behaviour sanitizers on. This is where a mis-scaled ADC reading or a guard that
does not hold gets caught; on the bench both look like a hardware fault.

## Talking to it

JSON-RPC 2.0 over USB CDC, one request per line, one response per line.

```bash
printf '{"jsonrpc":"2.0","id":1,"method":"fixture.channels"}\n' > /dev/tty.usbmodemXXXX
```

`openrpc.json` is the full contract. Start with `fixture.info` and `fixture.channels`: between
them they say which DUT signal every channel lands on, so an agent needs no other map.

Two notifications arrive unasked: `fixture.ready` once at start-up, and `uart.data` for every
channel configured to stream.

## Channels

### GPIO

| Channel | Pin | Direction | Probes | Notes |
|---|---|---|---|---|
| `tc1_cs` | GPIO6 | input | TC1_CS | TC1_CS -- DUT output: the controller drives chip select. Mastering this bus from the fixture requires the DUT held in reset via ESP32_EN first, and is not configured here |
| `tc1_drdy` | GPIO7 | input | TC1_DRDY | TC1_DRDY -- front-end output: MAX31856 data-ready |
| `tc1_fault` | GPIO8 | input | TC1_FAULT | TC1_FAULT -- front-end output: MAX31856 ~FAULT. Already an input in the draft, and correct |
| `ssr1` | GPIO9 | input | SSR1 | SSR1 -- DUT output: SSR gate drive from the controller |
| `heat_en` | GPIO10 | input | HEAT_EN | HEAT_EN -- DUT output: the charge-pump square wave (SYS-SAF-02) |
| `pump_node` | GPIO11 | input | PUMP_NODE | PUMP_NODE -- DUT output: charge-pump node, and analogue rather than logic |
| `heat_en_dc` | GPIO12 | input | HEAT_EN_DC | HEAT_EN_DC -- DUT output: the rectified charge-pump rail, analogue |
| `coil_drv` | GPIO13 | input | COIL_DRV | COIL_DRV -- DUT output: contactor coil drive |
| `alarm` | GPIO14 | input | ALARM | ALARM -- DUT output: buzzer drive |
| `enc_a` | GPIO15 | open_drain, active low | ENC_A | ENC_A -- DUT input: encoder channel A, simulated by the fixture |
| `enc_b` | GPIO16 | open_drain, active low | ENC_B | ENC_B -- DUT input: encoder channel B, simulated by the fixture |
| `enc_btn` | GPIO17 | open_drain, active low | ENC_BTN | ENC_BTN -- DUT input: encoder push button |
| `tc1_p` | GPIO18 | input | TC1_P | TC1_P -- thermocouple input, millivolts. NEVER driven. Injecting a temperature needs a calibrated mV source the fixture does not have; the probe is placed so one can be added |
| `tc1_n` | GPIO19 | input | TC1_N | TC1_N -- thermocouple input, millivolts. NEVER driven, as TC1_P |
| `curr_sense` | GPIO20 | input | CURR_SENSE | CURR_SENSE -- CT conditioning output, analogue. Should become an ADC channel once the divider scale is taken from the schematic; left as an observed input rather than inventing a scale |
| `esp32_en` | GPIO21 | open_drain, active low | ESP32_EN | ESP32_EN -- DUT input: controller reset, active low |
| `esp32_io0` | GPIO22 | open_drain, active low | ESP32_IO0 | ESP32_IO0 -- DUT input: controller boot strap, active low |
| `coil_permit` | GPIO23 | input | COIL_PERMIT | COIL_PERMIT -- DUT output: the supervisor's permit line (SWR-SAF-38) |
| `supervisor_reset` | GPIO24 | open_drain, active low | SUPERVISOR_RESET | SUPERVISOR_RESET -- DUT input: supervisor reset, active low |

### Analogue

| Channel | Pin | ADC | Divider | Probes | Expected |
|---|---|---|---|---|---|
| `ch_5v` | GPIO40 | ADC0 | 2.0:1 | +5V | 3.3 V |
| `ch_3_3v` | GPIO41 | ADC1 | 2.0:1 | +3.3V | 3.3 V |

### Buses

| Channel | Peripheral | Pins | Probes | Settings |
|---|---|---|---|---|
| `supervisor_uart` | uart0 | rx=GPIO1 | rx=SUPERVISOR_TX | 115200 baud, streaming |
| `i2c_i2c` | i2c0 | scl=GPIO5, sda=GPIO0 | scl=I2C_SCL sda=I2C_SDA | 400000 Hz |
| `spi_spi` | spi0 | rx=GPIO4, sck=GPIO2, tx=GPIO3 | rx=SPI_MISO sck=SPI_SCK tx=SPI_MOSI | 1000000 Hz, mode 0, master |

## Guards

A bus whose lines the DUT also drives is declared with a `guard`: the fixture refuses to master
it until that GPIO channel is asserted. It is an interlock, not a substitute for the series
resistors on the fixture board -- but it stops the ordinary mistake, which is an agent probing
an Ethernet bus while the DUT's own controller is mid-transaction.

## Regenerating

```bash
pinside generate kilncontrol-fixture.json --out .
```

Everything here is overwritten. Change the config, not the firmware.

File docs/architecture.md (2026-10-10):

<!--
SPDX-FileCopyrightText: 2026 Bitcrush Testing
SPDX-License-Identifier: GPL-3.0-or-later
-->

# Safe Kiln Controller, Software Architecture

| | |
|---|---|
| **Document** | Software Architecture Description |
| **Project** | Safe Kiln Controller, PID kiln controller |
| **Version** | 0.1 (draft) |
| **Date** | 2026-09-26 |
| **Status** | For review |
| **Derives from** | [`03_software_req.sdoc`](03_software_req.sdoc) v0.1 |
| **License** | GPL-3.0-or-later |

---

## 1. Purpose and scope

This document describes how the software satisfies [`03_software_req.sdoc`](03_software_req.sdoc).
It defines the decomposition into components, the dependency rules between them,
the runtime (task) structure, the data and persistence design, the algorithms of
the control and safety subsystems, and the build and test architecture.

Requirement identifiers are cited as `SWR-CTL-07`, `SWR-SAF-07`, `SWR-TST-01` and so on.
[§15](#15-traceability) maps requirement groups to the components and test levels
that realise and verify them.

## 2. Architectural drivers

Ranked. Where drivers conflict, the higher one wins, and the conflict is recorded
as a decision in [§3](#3-key-decisions).

| # | Driver | Source | Architectural consequence |
|---|---|---|---|
| 1 | **A single failure must not heat the kiln uncontrolled.** | `SYS-SAF-01`, `SYS-SAF-02` | A safety supervisor that is independent of, and has authority over, the control path; heat enable that decays unless actively refreshed. |
| 2 | **Everything that decides must be testable without hardware.** | `SWR-TST-01`–`SWR-TST-14` | Ports-and-adapters split: a pure-logic core with no peripheral, RTOS or clock access, driven in tests by a plant simulator. |
| 3 | **Control and safety must meet hard deadlines regardless of load.** | `SWR-NFR-01`–`SWR-NFR-04` | Core affinity split, priority ordering, no blocking calls on the control path, message passing instead of shared locks. |
| 4 | **No SD card, no external database, no external host.** | `UR-CON-03`, `SWR-WEB-02` | Log store as a raw circular flash partition; web assets embedded and gzipped in the firmware image; charting rendered client-side from the device's own API. |
| 5 | **Fits an 8 MB / no-PSRAM ESP32-S3 and runs for a week.** | `SWR-NFR-10`–`SWR-NFR-14` | Fixed-size records, static allocation in the core, bounded HTTP buffers, flash write pattern designed against an endurance budget. |
| 6 | **GPL-3.0-or-later, self-contained, dependencies pinned.** | `UR-CON-04` | Web assets vendored. One managed component (`espressif/mdns`), pinned exactly with the content hash in a committed lockfile; third-party licences audited and recorded in the SBOM. |

## 3. Key decisions

The 21 decisions this architecture rests on live in
[`04_software_arch.sdoc`](04_software_arch.sdoc), not here.

They moved because they are the part of the architecture that has identity: a
stable ID each, cited over a hundred times from the firmware, and a requirement
behind each one. In StrictDoc that last part is a `Satisfies` relation which is
checked when the document is built, so a decision can no longer cite a
requirement that does not exist, and
[`03_software_req.sdoc`](03_software_req.sdoc) can be read in the other direction --
from a clause to whatever implements it.

Everything else about the architecture stays in this document. None of it has
an ID, so there is nothing for a tool to check, and the diagrams are better
read rendered than quoted inside a field.

## 4. Layering and dependency rules

```mermaid
flowchart TD
    subgraph L4["Presentation"]
        WEB["kiln_web<br/>HTTP, REST, SSE, assets"]
        HMI["kiln_hmi<br/>screens, menu, encoder UX"]
    end
    subgraph L3["Application / orchestration"]
        APP["kiln_app<br/>tasks, run controller, event bus, wiring"]
    end
    subgraph L2["Domain core, no hardware, no RTOS, no clock"]
        CORE["kiln_core"]
        PID["pid"]
        SPG["setpoint"]
        PROF["profile"]
        SAFE["safety"]
        TUNE["autotune"]
        REC["logrec"]
        CFG["configmodel"]
    end
    subgraph L1["Ports, interface headers only"]
        PORTS["kiln_ports"]
    end
    subgraph L0["Adapters"]
        HAL["kiln_hal_esp32s3<br/>MAX31856, SSD1306, encoder,<br/>outputs, flash log, NVS, clock"]
        SIM["kiln_sim<br/>plant model + fault injection"]
    end

    WEB --> APP
    HMI --> APP
    APP --> CORE
    APP --> PORTS
    CORE --> PORTS
    HAL -.implements.-> PORTS
    SIM -.implements.-> PORTS
    CORE --- PID
    CORE --- SPG
    CORE --- PROF
    CORE --- SAFE
    CORE --- TUNE
    CORE --- REC
    CORE --- CFG
```

**Rules**, enforced at build time (`SWR-TST-07`):

1. `kiln_core` may include only C standard library headers and `kiln_ports` headers. Any `esp_*`, `freertos/*`, `driver/*` or `<time.h>` clock call in `kiln_core` is a build failure.
2. `kiln_ports` contains headers only, no `.c` files, no implementation.
3. Nothing depends on `kiln_hal_esp32s3` or `kiln_sim` except the composition root in `kiln_app` (and the test harnesses).
4. `kiln_web` and `kiln_hmi` never touch `kiln_core` state directly; they go through `kiln_app`'s command and query interface.
5. Dependencies are acyclic.

## 5. Component catalogue

### 5.1 Domain core (`kiln_core`)

| Component | Responsibility | Depends on | Verified by |
|---|---|---|---|
| `pid` | PID computation: P/I/D terms, anti-windup, derivative on measurement, bumpless transfer, output clamping. Pure function of state + inputs + `dt`. |, | Host unit, host integration |
| `setpoint` | Executes a profile: advances segment index, ramps the setpoint, applies hold-back, enforces dwell tolerance and acknowledgement gates, computes remaining and predicted end times. Those estimates assume the kiln keeps up, and are **optimistic through a cooling segment**: `SWR-CTL-13` makes cooling ramps passive, so a real kiln cools as fast as it cools rather than at the rate the program names. The API and the UI say so. | `profile` | Host unit, host integration |
| `profile` | Program data model, validation, duration prediction, JSON encode/decode. | `configmodel` (for limits) | Host unit |
| `safety` | All detection rules of requirements `SWR-SAF-04`–`SWR-SAF-13` and the current-based relay rules `SWR-SAF-25`–`SWR-SAF-30`, including the weld-discrimination sequence of `SWR-SAF-27`. Consumes a plant snapshot, emits a verdict: heat permitted or a specific fault. Stateful (timers, baselines) but pure. | `configmodel` | Host unit, host integration, fault-injection suite |
| `autotune` | Relay-autotune state machine, peak detection, cycle qualification, `Ku`/`Tu` identification, gain-rule application. | `pid` (types only) | Host unit, host integration |
| `window` | Duty → on/off decision for the current 10 ms tick, honouring minimum on/off time. |, | Host unit |
| `tempfilt` | First-order filter, calibration, rate-of-change regression. |, | Host unit |
| `current` | RMS accumulation over whole mains cycles, window gating and settle handling, CT calibration, reference-current learning, deviation and wear tracking. Pure: fed raw ADC samples plus the window phase. |, | Host unit, integration |
| `logrec` | Log record and sector-header encode/decode, CRC, torn-record detection, decimation with extrema preservation. |, | Host unit (incl. fuzz) |
| `logring` | The circular store itself (`SWA-19`): head discovery, wrap and erase ordering, torn-record handling, run selection, store statistics. Pure logic over `port_flash`. | `logrec` | Host unit (incl. power-cut injection) |
| `configmodel` | Configuration schema: item table with type, unit, range, default; validation; versioned migration; JSON projection. |, | Host unit |
| `runstate` | Run record model; reconstruction of resume state from a log tail. | `logrec`, `profile` | Host unit |
| `faults` | Fault and warning code tables with descriptions ([requirements Appendix A](03_software_req.sdoc)). |, | Inspection + code-generated consistency test |

### 5.2 Ports (`kiln_ports`)

Each is a struct of function pointers plus an opaque context, so that a test
double is a compile-time-checked substitution.

| Port | Operations | Adapters |
|---|---|---|
| `port_tc` | `configure(type, filter_hz)`, `read(→ temp_c, cj_c, fault_bits)` | MAX31856; simulator; fault-injecting stub |
| `port_heat` | `set_duty(permille)`, `enable_refresh()`, `force_off()` | GPIO + 10 ms timer; simulator; recording spy |
| `port_alarm` | `set(pattern)` | GPIO and a one-shot timer, stepping the rhythm table of `kiln_core/alarmptn` (§10.7); spy |
| `port_display` | `blit(framebuffer)`, `set_contrast()`, `present()` | SSD1306 over I²C; in-memory framebuffer for golden-image tests |
| `port_input` | `poll(→ events)` | PCNT + GPIO; scripted event source |
| `port_current` | `start_burst(window_phase)`, `read_burst(→ samples, n)`, `present()` | ADC continuous-mode DMA burst; simulator; scripted sample source |
| `port_clock` | `now_monotonic_us()`, `now_wall_utc()`, `wall_valid()` | `esp_timer` + SNTP; virtual clock driven by the test |
| `port_flash` | `info()`, `read()`, `write()`, `erase()` | `esp_partition`; RAM fake with NOR semantics and power-cut injection |
| `port_logstore` | `append(record)`, `iterate(range, cb)`, `stats()`, `erase_all()` | `kiln_core/logring` over `port_flash` (`SWA-19`) |
| `port_counters` | `load()`, `add_contactor_ops()`, `add_ssr_ops()`, `flush()` | NVS with RAM accumulation (`SWR-CUR-13`); spy |
| `port_system` | `reset_cause()`, `fw_info()`, `stats()`, `wdt_subscribe/feed()` | `esp_system` + task WDT; stub |
| `port_update` | `check()`, `fetch()`, `begin/write/finish()`, `confirm_running()`, `rollback()` | `esp_https_ota` for the pull path of §13.5, `esp_ota_ops` for the slots; stub |
| `port_kvstore` | `get/set/erase(namespace, key, blob)` | NVS; in-memory fake |
| `port_filestore` | `read/write_atomic/remove(path)`, `usage` | `kiln_core/fileslots` over `port_flash` (`SWA-21`); RAM fake on host |
| `port_net` | `status()`, `scan_begin/busy/results()`, `connect()` | WiFi station, scanning and joining (§5.4), plus SNTP; stub. **No access point**: network setup is on the display |

### 5.3 Application (`kiln_app`)

| Component | Responsibility |
|---|---|
| `composition` | The only place that binds ports to concrete adapters. One function; the test harnesses provide their own. |
| `run_controller` | The mode state machine of [requirements §2.2](03_software_req.sdoc). Owns the transition rules, start-up self-check, pause/resume/abort, completion, fault latching and acknowledgement, and power-loss recovery policy. |
| `control_task` | Per-cycle orchestration: read sensors, publish snapshot, advance setpoint, run PID, publish duty, emit log sample. |
| `safety_task` | Per-cycle safety evaluation and the heat-enable refresh. The only writer of heat authority. |
| `event_bus` | Fan-out of state changes, faults, warnings and telemetry to subscribers (logger, HMI, SSE). Bounded queues, non-blocking publish, drop-with-count on overflow. |
| `telemetry` | Maintains the current published snapshot for queries, lock-free for readers. |
| `logger_task` | Drains the log queue to `port_logstore`; the only component that blocks on flash. |
| `settings` | Configuration load, validate, migrate, apply, persist; marks reboot-required items. |
| `run_index` | Run record persistence and the 20-run retention policy. |

### 5.4 Presentation

| Component | Responsibility |
|---|---|
| `kiln_hmi` | Screen composition into a framebuffer, font and layout, menu and confirmation flows, encoder event interpretation, fault screen precedence. Rendering logic is pure and produces a framebuffer, so screens are verifiable by golden-image comparison on the host. |
| `kiln_web` | `esp_http_server` wiring, route table, request parsing and bounded buffering, authentication, JSON serialisation, SSE stream, OTA endpoint, embedded asset serving. |
| `web/` (browser) | Dashboard, chart, program editor, config, run history. Plain ES modules, no framework, no runtime dependency ([`SWR-WEB-02`](03_software_req.sdoc)). |

## 6. Runtime view

### 6.1 Tasks

| Task | Core | Prio | Trigger | Period | Stack | Blocking allowed? |
|---|---|---|---|---|---|---|
| `heat_window` | 1 | timer ctx | `esp_timer` | 10 ms |, | **No** |
| `safety` | 1 | 20 | timer | 100 ms | 3 kB | No |
| `control` | 1 | 18 | timer | 250 ms … 5 s (cfg, default 1 s) | 4 kB | No |
| `acquire` | 1 | 19 | timer | 250 ms | 3 kB | SPI only, bounded |
| `current` | 1 | 17 | burst complete | per output window | 3 kB | No (DMA completion) |
| `logger` | 0 | 8 | queue | on demand | 3 kB | Yes (flash) |
| `hmi` | 0 | 6 | timer | 100 ms | 4 kB | I²C only, bounded |
| `httpd` | 0 | 5 | socket |, | 8 kB | Yes |
| `net` | 0 | 4 | events |, | 4 kB | Yes |

Rationale for the ordering: `safety` outranks everything so its verdict is never
late (`SWR-SAF-13`, `SWR-NFR-03`); `acquire` outranks `control` so a control cycle always
sees a fresh sample; both sit on core 1 where the WiFi stack (priority 23 on
core 0) cannot reach them (`SWA-15`, `SWR-NFR-02`).

### 6.2 Normal control cycle

```mermaid
sequenceDiagram
    autonumber
    participant AQ as acquire (250 ms)
    participant TEL as telemetry
    participant CT as control (1 s)
    participant SG as setpoint
    participant PID as pid
    participant SF as safety (100 ms)
    participant HW as heat_window (10 ms)
    participant LG as logger

    AQ->>AQ: port_tc.read() x2, decode faults
    AQ->>AQ: tempfilt: calibrate, filter, rate
    AQ->>TEL: publish snapshot (PV, case, rate, faults)

    CT->>TEL: read snapshot
    CT->>SG: tick(dt, PV) -> SP, segment, holdback
    CT->>PID: update(SP, PV, dt) -> duty_request
    CT->>TEL: publish SP, duty_request, PID terms
    CT->>LG: enqueue sample (on log interval)

    SF->>TEL: read snapshot + duty_request
    SF->>SF: evaluate SWR-SAF-04..SWR-SAF-13
    alt all rules pass
        SF->>HW: set_duty(duty_request)
        SF->>HW: enable_refresh()  %% toggles charge pump
    else any rule trips
        SF->>HW: force_off()
        SF->>SF: latch fault, publish event
    end

    loop every 10 ms
        HW->>HW: window: on/off for this tick, min on/off time
    end
```

Note the direction of authority: the control task **requests** a duty; the safety
task is what actually applies it and refreshes the enable. That is `SWA-04`
realised in the call graph.

### 6.3 Fault reaction

```mermaid
sequenceDiagram
    autonumber
    participant SF as safety
    participant HW as heat_window
    participant RC as run_controller
    participant LG as logger
    participant BUS as event_bus

    SF->>SF: rule trips (e.g. SWR-SAF-07 runaway)
    SF->>HW: force_off()  %% duty = 0
    SF->>SF: stop enable_refresh()  %% contactor opens <= 1 s
    SF->>BUS: fault(code, snapshot)
    BUS->>RC: fault
    RC->>RC: state := Fault (latched)
    RC->>LG: persist latched fault (survives power loss, SWR-SAF-17)
    BUS->>LG: event record
    BUS-->>HMI: fault screen (takes precedence)
    BUS-->>WEB: SSE fault event -> banner
    RC->>RC: alarm pattern = fault
```

Worst-case latency to zero duty: one safety period (100 ms) plus one window tick
(10 ms) = **110 ms**, inside the 500 ms of `SWR-NFR-04`. Contactor release is the
charge-pump decay, specified at ≤ 1 s.

### 6.4 Startup

```mermaid
flowchart TD
    A["Reset"] --> B["Outputs to safe state<br/>(pull-downs + first instruction)"]
    B --> C["Read reset cause, record if abnormal (SWR-NFR-15)"]
    C --> D["Init NVS, load + migrate config (SWR-CFG-05)"]
    D --> E["Mount file store, log store; scan ring head"]
    E --> F["Bind ports to adapters (composition)"]
    F --> G["Start acquire + safety tasks"]
    G --> H{"Latched fault<br/>in storage?"}
    H -->|yes| I["Enter Fault, show cause"]
    H -->|no| J{"Run interrupted?"}
    J -->|yes| K["Apply SWR-RUN-08 recovery policy<br/>using log tail (SWA-09)"]
    J -->|no| L["Enter Idle"]
    K --> L
    I --> M["Start HMI, web, net (core 0)"]
    L --> M
```

Safety supervision is running before networking, the HMI or the web server are
started, so there is no window in which heating could be enabled without
supervision (`SWR-NFR-09`, `SWR-SAF-21`).

## 7. Control subsystem

### 7.1 Setpoint generator

State: `{segment_index, phase, segment_elapsed_s, sp_c, holdback_active}` where
`phase ∈ {ramp, dwell, await_ack, done}`.

Per tick, with `dt` in seconds:

```
if holdback enabled and |sp_c - pv_c| > holdback_band:
        holdback_active = true                      # SWR-CTL-11
        # sp_c and segment_elapsed_s are both frozen
        return

holdback_active = false

if phase == ramp:
        if rate == 0:                               # SWR-CTL-10: "as fast as possible"
                sp_c = target_c
        else:
                step = rate * dt / 3600.0
                sp_c = move_toward(sp_c, target_c, step)
        if sp_c == target_c:
                phase = dwell; segment_elapsed_s = 0

elif phase == dwell:
        if |pv_c - target_c| <= dwell_tol_c:        # SWR-CTL-12
                segment_elapsed_s += dt
        if segment_elapsed_s >= dwell_s:
                phase = await_ack if segment.requires_ack else advance()

sp_c = min(sp_c, cfg.max_temp_c)                    # SWR-SAF-23
```

A cooling segment (`target_c < pv_c`) ramps the setpoint downward and the PID's
own 0 % floor makes it passive; no negative duty exists (`SWR-CTL-13`).

Both remaining-time and predicted-end-time are computed by running this same
generator forward over a copy of the state with the current PV held constant , 
one algorithm, one set of tests, no second estimator to drift out of agreement.

### 7.2 PID

Parallel form, explicit units so that stored gains are unambiguous:

| Gain | Unit | Range | Default |
|---|---|---|---|
| `Kp` | % duty per °C | 0 … 100 | 2.0 |
| `Ki` | % duty per (°C·s) | 0 … 10 | 0.01 |
| `Kd` | % duty·s per °C | 0 … 10 000 | 40.0 |

```
e      = sp - pv
P      = Kp * e
I     += Ki * e * dt                       # conditionally, see below
D      = -Kd * (pv - pv_prev) / dt         # SWR-CTL-04: derivative on measurement
u_raw  = P + I + D
u      = clamp(u_raw, 0, duty_max)         # SWR-CTL-16

# SWR-CTL-05 anti-windup: integrate only when it does not push further into saturation
if (u_raw > duty_max and e > 0) or (u_raw < 0 and e < 0):
        undo the integration for this cycle
I      = clamp(I, 0, duty_max)
```

On a mode change the integral is back-calculated as `I := u_current - P - D` so
the output is continuous (`SWR-CTL-06`). `pv_prev` is seeded on the first cycle so
no derivative spike occurs at start. All of `P`, `I`, `D`, `e`, `u_raw` and the
saturation flag are published for logging and diagnostics (`SWR-CTL-15`).

### 7.3 Time-proportional output

The control task publishes `duty_permille` atomically. The 10 ms timer callback
owns the window:

```
tick_in_window = (tick + 1) % ticks_per_window     # window 0.5..30 s, default 2 s
want_on        = tick_in_window * 1000 < duty_permille
want_on        = apply_min_times(want_on, since_change_ms,
                                 min_on_ms, min_off_ms)   # SWR-CTL-08
if not heat_authorised:                                    # SWA-04
        want_on = false
gpio_set(SSR_PIN, want_on)
```

With a 2 s window and a 10 ms tick the resolution is 0.5 % duty, and on a 50 Hz
supply every `on` interval covers a whole number of half-cycles of a zero-cross
SSR. `apply_min_times` is pure logic in `window` and is unit-tested exhaustively
across the duty range against the minimum-time constraints.

### 7.4 Autotune

```mermaid
stateDiagram-v2
    [*] --> Approach
    Approach --> Settle: pv within hysteresis of sp_tune
    Settle --> Relay: rate of change below threshold
    Relay --> Relay: record peak / trough
    Relay --> Identify: >= 4 cycles, first discarded,<br/>periods within 15%, amplitudes within 20%
    Identify --> Present: Ku, Tu, candidate gain sets
    Present --> [*]: operator accepts or discards
    Approach --> Failed: timeout / safety trip / cancel
    Settle --> Failed: timeout / safety trip / cancel
    Relay --> Failed: timeout / safety trip / cancel
    Failed --> [*]: gains unchanged (SWR-TUN-08)
```

In `Relay`, the output is bang-bang about the tuning setpoint with amplitude `d`
and hysteresis `h`: `u = d` while `pv < sp_tune - h`, `u = 0` while
`pv > sp_tune + h`. Peaks and troughs are detected with the same hysteresis to
reject noise. From the qualified cycles, with `a` the half-amplitude of the
process oscillation in °C and `d` the relay half-amplitude in % duty:

$$K_u = \frac{4d}{\pi a}, \qquad T_u = \text{mean cycle period}$$

Gain rules (`SWR-TUN-06`), with `Ki = Kp / Ti` and `Kd = Kp · Td`:

| Rule | `Kp` | `Ti` | `Td` | Character |
|---|---|---|---|---|
| Ziegler–Nichols (PID) | `0.60 · Ku` | `0.50 · Tu` | `0.125 · Tu` | Fast, overshoots |
| **Tyreus–Luyben (PID)**: default | `Ku / 2.2` | `2.2 · Tu` | `Tu / 6.3` | Conservative, low overshoot, suited to a slow, high-inertia kiln and to `SWR-NFR-08` |

Both sets are presented; nothing is stored until the operator accepts
(`SWR-TUN-09`), and the accepted set is recorded with its provenance
(`SWR-TUN-11`). Safety supervision is fully active throughout, autotune is just
another duty requester, subject to the same authority.

## 8. Safety subsystem

### 8.1 Authority model

```mermaid
flowchart LR
    CT["control / autotune / manual<br/>duty_request"] --> SF
    AQ["acquire<br/>PV, case, rate, TC faults"] --> SF
    SF["safety supervisor<br/>(100 ms, core 1, prio 20)"]
    SF -->|"set_duty"| SSR["SSR pin<br/>(10 ms window)"]
    SF -->|"toggle each cycle"| CP["charge pump"]
    CP --> CON["contactor coil"]
    CON --> MAINS["heater circuit"]
    CUT["independent hardware<br/>over-temp cutout (SYS-HW-13)"] --> MAINS
    WDT["task + RTC watchdog"] -.->|"kills a stuck safety task"| CP
```

Three independent things must all hold for the kiln to heat: the safety
supervisor must be running and toggling, the SSR must be commanded on, and the
hardware cutout must be closed. No software path can satisfy more than the first
two, and a crashed or hung MCU satisfies none.

### 8.2 Rule table

Every rule is a pure function of the snapshot plus its own timer state, so each
row below is one host test (`SWR-TST-09`, `SWR-TST-23`).

| Req | Rule | Inputs | Default thresholds | Action |
|---|---|---|---|---|
| `SWR-SAF-31` | Door interlock open | door switch | heat off **immediately**; latch after 0.2 s | Latch 27, drop contactor |
| `SWR-SAF-04` | TC fault persists past grace | fault bits, comms status | 5 s grace | Latch 1–5, 16 |
| `SWR-SAF-05` | Reversed TC | PV falling while duty high | falling while duty > 50 % | Latch 6 |
| `SWR-SAF-06` | Stuck sensor | ΔPV over window, duty | < 2 °C over 10 min at > 50 % | Latch 7 |
| `SWR-SAF-07` | Runaway / heating failure | duty, rate of rise | > 80 % for 15 min with rate < 10 °C/h | Latch 8 |
| `SWR-SAF-08` | Uncommanded heating | duty, ΔPV | +5 °C over 3 min at 0 % duty, after a 60 s settle | Latch 9, open contactor |
| `SWR-SAF-09` | Over-temperature | PV, `max_temp` | at limit → heat off; +10 °C → latch | Latch 10 |
| `SWR-SAF-10` | Setpoint excursion | PV − SP | > 50 °C for 2 min | Latch 11 |
| `SWR-SAF-11` | Enclosure over-temperature | case PV | > 70 °C | Latch 12 |
| `SWR-SAF-12` | Insulation degradation | energy-to-temperature vs. baseline | > 1.3 × baseline | **Warning 101** only |
| `SWR-SAF-13` | Deadline missed | cycle timestamps | > 2 × period | Latch 13 / 14 |
| `SWR-SAF-25` | Relay fail-on | current in an off-window | > 0.5 A for 2 windows | Latch 21, drop contactor |
| `SWR-SAF-26` | Relay/element fail-off | current in an on-window | < 20 % of reference for 30 s | Latch 23 |
| `SWR-SAF-27` | Weld discrimination | current after contactor dropped | persists > 2 s | Latch 22 (welded) else 21 (SSR) |
| `SWR-SAF-28` | Current deviation | current vs. run reference | warn 10 %, latch 25 % | Warning 112 / Latch 24 |
| `SWR-SAF-29` | Over-current | current | > 120 % of nominal | Latch 25 |
| `SWR-SAF-30` | Relay wear | switch counts, intermittent mismatches | configurable life limit | **Warning 109 / 110** only |
| `SWR-SAF-14` | Watchdog | task WDT, RTC WDT | per task deadline | Reset; charge pump decays |
| `SWR-SAF-15` | Brownout | brownout detector | IDF default | Reset to safe state |

The insulation baseline of `SWR-SAF-12` is established from the run history: the
median duty-seconds required to pass each 100 °C boundary across previous
comparable runs, stored in the run index.

`SWR-SAF-31` is evaluated **first**, ahead even of `SWR-SAF-13`. It is the only rule that
needs no history, no timer and no trust in any other reading: a door that is
open is a fact, where every other row is an inference from a measurement. It is
also the only rule with an unconditional tier, heat is withheld and the
contactor dropped on the *first* open sample, and only the latch waits for the
confirmation window. An implementation that waited 200 ms before dropping the
heater would satisfy the latch test and miss the requirement, so the two tiers
are tested separately.

Note what the table cannot show: `SYS-HW-21` requires the same switch to be wired
in series with the contactor coil as well. The row above is the controller's
*knowledge* of the door, which is what latches, annunciates and logs; the
interlock itself is hardware, and works whether or not this firmware does. The
argument is `SWA-05`'s, applied to a second input.

Two parameters in the table deserve their own note, because both change when the
rule is active rather than merely how sensitive it is:

- **`SWR-SAF-08`'s settle delay** (`uncommanded_settle_s`, default 60 s). After a spell
  at high duty the measured temperature keeps climbing for a while as heat soaks
  inward from the elements, and arming immediately would read that as a shorted
  SSR. The consequence is worth stating plainly: during a normal firing duty is
  rarely zero for a full minute, so **`SWR-SAF-08` is effectively inactive while
  running**. That is precisely why `SWR-SAF-25`: which sees the same failure in amps,
  inside a second, is the primary detection and `SWR-SAF-08` the backstop for a kiln
  whose current monitoring is off or whose transformer has failed (`SWR-CUR-12`).
- **`SWR-SAF-05`'s confirmation window** (`reversed_confirm_s`, default 30 s). The drop
  must persist, not merely occur. A kiln with transport lag whose gains are
  imperfect overshoots and then coasts down several degrees while the controller
  is already pushing duty back up; an instantaneous test reads that as a reversed
  probe and stops a healthy firing. A genuinely reversed couple falls
  monotonically and does not come back, so the confirmation costs it nothing.

### 8.3 Fault latching

A latched fault is written to NVS with its code, a snapshot and a timestamp
before the alarm sounds, so an immediate power loss cannot lose it (`SWR-SAF-17`).
Clearing requires an explicit operator acknowledgement, and the acknowledgement
is refused while the triggering rule still evaluates true (`SWR-SAF-18`), the same
rule function is reused for that check, so there is no second implementation to
disagree.

## 9. Data model

All temperatures are °C internally and in the API; display conversion to °F is
presentation-only (`SWR-HMI-13`).

```c
/* A firing program. 8 bytes per segment; 32 segments max (SWR-PRG-01/02). */
typedef struct {
    uint16_t target_c;        /* 0 .. 1350                                    */
    uint16_t rate_c_per_h;    /* 0 = maximum rate (SWR-CTL-10)                 */
    uint16_t dwell_min;       /* 0 .. 5999                                    */
    uint8_t  flags;           /* bit0: requires operator acknowledgement      */
    uint8_t  reserved;
} kiln_segment_t;

typedef struct {
    char           name[32];
    char           description[96];
    uint8_t        segment_count;   /* 1 .. 32                                */
    uint8_t        flags;           /* bit0: read-only example (SWR-PRG-09)    */
    uint16_t       schema_version;
    kiln_segment_t segments[32];
} kiln_program_t;

/* Immutable per-cycle view of the plant, passed between tasks (SWA-13). */
typedef struct {
    uint64_t t_mono_us;
    float    kiln_c, kiln_c_raw, case_c, cj_c;
    float    rate_c_per_h;
    float    setpoint_c;
    uint16_t duty_permille;
    float    current_a;            /* last valid RMS measurement             */
    float    current_ref_a;        /* run reference, SWR-CUR-08               */
    uint8_t  current_flags;        /* conduction / leakage / skipped / stale */
    uint16_t tc_fault_bits, case_fault_bits;
    uint8_t  state, segment_index, segment_count;
    bool     heat_authorised, holdback_active, duty_saturated;
} kiln_snapshot_t;

/* What identifies a run; kept in the run index, not in the sample log. */
typedef struct {
    uint32_t       run_id;
    uint64_t       start_utc, end_utc;
    uint8_t        end_reason;      /* completed / aborted / fault / power loss */
    uint8_t        fault_code;
    float          kp, ki, kd;
    float          current_ref_a;         /* SWR-CUR-08, baseline for SWR-SAF-28     */
    uint32_t       contactor_ops, ssr_ops;/* SWR-CUR-13 wear counters           */
    uint32_t       first_seq, last_seq;   /* extent in the log ring            */
    bool           samples_truncated;     /* SWR-LOG-09                         */
    kiln_program_t program_as_run;        /* SWR-PRG-11                         */
} kiln_run_record_t;
```

## 10. Persistence

### 10.1 Partition table

For an 8 MB device (`SWR-NFR-13`); a 16 MB device enlarges only the log partition.

| Name | Type | Size | Purpose |
|---|---|---|---|
| bootloader + table |, | 64 kB |, |
| `nvs` | data/nvs | 24 kB | Configuration, latched fault, WiFi credentials |
| `otadata` | data/ota | 8 kB | OTA selector |
| `phy_init` | data/phy | 4 kB | RF calibration |
| `ota_0` | app | 2 MB | Application slot A (`SWR-UPD-02`) |
| `ota_1` | app | 2 MB | Application slot B |
| `kilnfs` | data (custom) | 512 kB | Programs and run records (`SWA-21`) |
| `kilnlog` | data (custom) | 2 MB | Circular sample log (`SWA-08`) |
| *(unallocated)* |, | ≈ 1.4 MB | Headroom |

### 10.2 Log record format

Fixed **20 bytes** (`SWA-18`), 4-byte aligned so `esp_partition_write` needs no
read-modify-write:

| Off | Size | Field | Encoding |
|---|---|---|---|
| 0 | 4 | `t_rel_ms` | ms since run start (49 days range) |
| 4 | 2 | `kiln_raw` | int16, 0.1 °C |
| 6 | 2 | `kiln_filt` | int16, 0.1 °C |
| 8 | 2 | `setpoint` | int16, 0.1 °C |
| 10 | 2 | `case_c` | int16, 0.1 °C |
| 12 | 2 | `current_ca` | uint16, 0.01 A (0…655 A) |
| 14 | 1 | `duty` | 0…200 = 0…100 % in 0.5 % steps |
| 15 | 1 | `segment` | 0…31, 0xFF = not applicable |
| 16 | 1 | `state_flags` | state in low nibble; hold-back, saturation, TC fault, wall-time-valid in high nibble |
| 17 | 1 | `current_flags` | conduction / leakage / skipped / stale / CT fault |
| 18 | 1 | `reserved` | 0, keeps the record 4-byte aligned |
| 19 | 1 | `crc8` | over bytes 0…18 |

`current_flags` is not optional padding: `SWR-CUR-04` means a given sample's
current may be a conduction measurement, a leakage measurement, or a window that
was too short to measure at all. Without the flag a reader cannot tell 0.0 A
"the relay is correctly off" from 0.0 A "we did not look".

Sector header, 16 bytes at the start of each 4 kB sector:

| Off | Size | Field |
|---|---|---|
| 0 | 4 | magic `"KLOG"` |
| 4 | 4 | `seq`: monotonic sector sequence number, defines ring order |
| 8 | 4 | `run_id` |
| 12 | 2 | `format_version` |
| 14 | 2 | `crc16` |

So each 4 kB sector holds `(4096 − 16) / 20 = 204` records.

### 10.3 Ring behaviour

- **Capacity:** `2 MB / 4 kB = 512` sectors × 204 = **104 448 records** = **290 h** at the default 10 s interval, against the 150 h of `SWR-LOG-07`.
- **Head discovery on boot:** read the 512 sector headers (8 kB total) and take the highest valid `seq`; then scan that sector for the first erased slot (all-`0xFF`). Bounded, fast, and needs no separate metadata to be consistent with the data.
- **Torn write:** a record whose `crc8` fails, or which is partially `0xFF`, terminates the scan of that sector and is skipped by readers (`SWR-LOG-08`). At most the one in-flight record is lost.
- **Wrap:** the next sector is erased immediately *before* it is first written, never in advance, so a power loss can never destroy data that the index still claims exists.
- **Non-blocking:** the control task enqueues; only `logger_task` touches flash (`SWR-LOG-14`). A full queue drops samples and increments a counter rather than stalling control.
- **Recovery (`SWA-09`):** the tail of the ring already carries setpoint, segment index and relative time every 10 s, which is exactly the state `SWR-RUN-08` needs.

### 10.4 Flash endurance analysis

One sector fills in `204 × 10 s = 34 min` of logging, so one erase per 34 min of
*running*. Continuous 24/7 operation for 10 years gives
`87 600 h / 34 min ≈ 154 600` sector erases spread over 512 sectors ≈ **302
erases per sector**: 0.6 % of the 100 000-cycle budget of `SYS-ASM-08`, and far
inside the 50 000 of `SWR-NFR-14`. Realistic hobby use (a few hundred hours a year)
is two orders of magnitude below that again.

`SWA-09` is what makes this hold: a naive 10 s run-state write to NVS would have
added ~60 000 writes per week-long run to a 24 kB partition.

### 10.5 Decimation

`GET /api/log` takes `max_points`. The store buckets the requested range into
`max_points` intervals and returns, per bucket, the first timestamp together with
the **minimum and maximum** of each series (`SWR-LOG-11`), so a brief excursion
survives downsampling instead of being averaged away. Decimation is in `logrec`
and is therefore host-tested, including the property that the extrema of the
decimated series equal the extrema of the full series.

### 10.6 The file store

`kilnfs` holds run records as a fixed array rather than a filesystem
(`SWA-21`). It held programs too until `SWR-PRG-04` was withdrawn; the store
below is unchanged, and what changed is that only one caller writes to it. The partition divides into equal **regions of two erase
sectors**, 64 regions in 512 kB. One file occupies one region and alternates
between its two sectors, so the copy being replaced is never the copy being
erased.

Within a sector:

| Offset | Size | Field | Written |
|---|---|---|---|
| 0 | 4 | magic `KFS1` | second |
| 4 | 4 | sequence number, higher wins | second |
| 8 | 2 | payload length | second |
| 10 | 2 | CRC-16 over the name field and the payload | second |
| 12 | 64 | name, NUL padded | first |
| 76 | up to 4020 | payload | first |

The two-stage write is the whole design. The name and payload go down in one
write and the twelve byte commit header in a second. A power cut before the
commit leaves the magic erased, so the half-written copy is not a copy at all
and the previous one still carries the highest sequence number. A power cut
*inside* the commit header is caught by the sequence number when it is torn
early and by the CRC when only the CRC is missing. There is no instant at which
a reader can see a torn file, which is what `SWR-RUN-08` needs.

On mount the store reads both copies of every region, validates each against its
CRC, and takes the higher sequence number. There is no separate metadata, so
nothing can disagree with the data. The loser is left in place rather than
erased, because it is the next write's target and erasing it at boot would spend
an erase cycle on every power-up.

A name longer than 63 bytes is **refused**, not truncated: `KILN_PATH_MAX` is 64
including the terminator and the stored name field is exactly that, so a longer
path returns `KILN_ERR_INVALID_ARG`. Both callers produce five-character slot
paths, so nothing generates one today; refusing is the answer because storing a
file under a name the caller did not ask for is worse than failing.

Capacity is 20 of 64 regions, for the run records of `SWR-LOG-09` and nothing
else. It was 40, half of them programs, until `SWR-PRG-04` was withdrawn and the
firing profiles moved into the image: the partition is now a third used rather
than two thirds. That is recorded and deliberately not acted on, because
shrinking it is a flash-layout change that breaks every device already flashed,
to recover space nothing needs. Endurance is generous for the same reason the
log's is: a run record is written once per firing, so a region sees single-digit
erases per year against a 100 000 cycle rating.

**Wear is handled at the write rather than at the read.** A NOR sector at the
end of its life does not report an error: it takes the write, returns success,
and holds something else. Every write is therefore read back and re-validated
through the same path a mount uses, and only then does the in-RAM index point at
it. A copy that does not verify retires its region, and the write is
re-attempted in a free region at a higher sequence number, up to three regions.
The caller gets success, because the file is stored; what changed is where.

Retirement needs no bad-block table. Once the migrated copy has verified the old
region is erased, best effort: if that succeeds the stale copy is gone, which is
what stops a later delete from being undone at the next mount, and the region
returns to the pool at the next boot, which is the right answer for a sector
that can still be erased. If the erase fails, which is what a sector that is
genuinely finished does, the stale copy stays at a *lower* sequence number, two
regions claim one name, and mount resolves it the only way it can be true: the
lower sequence number is the write that failed, its region is retired again, and
the higher one is the file. A power cut between the verify and the erase leaves
the same state and is resolved the same way. The count of retired regions is
logged at boot, and is the only warning anybody gets that the part is going.

What the store does **not** do is spread wear. A region is chosen by index and
keeps its file for as long as it works, because the endurance arithmetic above
has four orders of magnitude of headroom and levelling would be mechanism bought
for nothing. Retirement is in because its failure mode is losing a run record,
which is cheap to prevent and annoying to explain.

**What a mount costs**, measured in `test_fileslots` rather than estimated: the
medium this firmware produces, 20 run records of 554 bytes, costs **488 reads
and 31 888 bytes** of CRC. A partition full of
maximum-size files, both copies valid, costs **8 192 reads and 524 288 bytes**,
which is the whole partition. Both are paid once, at start-up, and the
expectation is tens of milliseconds rather than a budget item; if a board ever
says otherwise, the only thing mount needs eagerly is which copy of each region
wins, and the payload CRC could be deferred to the read. The numbers are
asserted so that making mount lazy cannot happen quietly.

Several properties carry the weight and each is a host test, driven through a
flash fake that enforces NOR semantics, can cut power part-way through a write,
and can model a worn sector that accepts a write and keeps zeros: a file
survives a remount, a cut before the commit leaves the previous copy, a cut
inside the commit header leaves the previous copy, a sector that lies about a
write retires its region and the file is still readable, a region that cannot be
erased stays retired across a reboot, and a part with nowhere left to write says
so instead of losing the previous content. The same fake drives `run_index`
over the real store in `test_stores_on_flash`, which is the combination that
runs on the board.

### 10.7 What the buzzer sounds like

The buzzer is a 5 V active part that makes its own tone (`SYS-HW-09`), so the
only thing the firmware chooses is the rhythm, and `SWR-SAF-20` asks for two
annunciations an operator can tell apart without looking.

| | Pattern | Cycle | Sounding |
|---|---|---|---|
| Completion | three 90 ms chirps, then silence | 5 s | 270 ms, 5 % |
| Fault | six 60 ms chirps, 400 ms gap, without end | 1.06 s | 360 ms, 34 % |

They differ in rhythm, in rate and in duty, which is what "distinguishable"
has to mean for a part with one tone and no volume control. Completion is a
notification: a firing that took nine hours has finished correctly, and
`hmi.alarm_duration_s` defaults to 4 s so the operator hears the burst once.
A fault is meant to be unpleasant and to carry through a wall, and it continues
until the fault is acknowledged, because a fault that stopped announcing itself
is a fault nobody heard.

The table and the stepper are in `kiln_core/alarmptn`, with no clock and no
hardware, so the rhythms are host-tested and the comparison between them is
asserted rather than described (`SWA-01`, `SWA-02`). The adapter sets a pin and
arms a one-shot timer for the interval it is handed; it was previously the whole
pattern, inside an `esp_timer` callback no test could reach. A pattern value
that is not one of the three is silent: the failure direction is off, because
an operator's only remedy for a buzzer stuck on is the mains switch.

## 11. Configuration

`configmodel` holds a static table, one row per item, with key, type, unit,
minimum, maximum, default, flags (`secret`, `reboot_required`, `locked_while_running`).
Everything else is derived from that table: NVS persistence, JSON projection for
the API, range validation, the web form, and the documentation table. Adding a
setting means adding one row (`SWR-CFG-01`–`SWR-CFG-04`, `SWR-CFG-08`).

A `schema_version` accompanies the stored blob. On load: equal version → use;
older → migrate, filling new items with defaults; newer or corrupt → defaults
plus warning (`SWR-CFG-05`). Items flagged `secret` are never serialised outward;
the API reports only `"set": true|false` (`SWR-CFG-07`).

## 12. Web subsystem

### 12.1 REST API

`Content-Type: application/json` throughout. Errors are
`{"error":{"code":"...","message":"..."}}` with a conventional status
(`SWR-WEB-20`). State-changing methods require authentication when a password is
set (`SWR-WEB-23`).

| Method | Path | Purpose | Req |
|---|---|---|---|
| `GET` | `/api/status` | Current snapshot, one-shot | `SWR-RUN-05` |
| `GET` | `/api/events` | **SSE** stream: `telemetry`, `state`, `fault`, `warning`, `tune` | `SWR-WEB-05` |
| `GET` | `/api/info` | Version, git revision, build time, target, uptime, gains + provenance | `SWR-UPD-06` |
| `GET` `PUT` | `/api/config` | Read / atomically write configuration | `SWR-CFG-03` |
| `POST` | `/api/config/defaults` | Restore defaults | `SWR-CFG-06` |
| `GET` | `/api/programs` | List the programs compiled into the firmware | `SWR-PRG-09` |
| `GET` | `/api/programs/{id}` | Read one; an id past the end is `404` | `SWR-PRG-09` |
| `GET` | `/api/programs/{id}/preview` | Predicted setpoint curve, duration, end time | `SWR-PRG-06` |
| `POST` | `/api/run` | Start `{program_id}` | `SWR-RUN-02` |
| `POST` | `/api/run/pause` `resume` `abort` `ack` | Run control and segment acknowledgement | `SWR-RUN-03/04`, `SWR-PRG-03` |
| `PATCH` | `/api/run/segments` | Edit remaining segments of a live run | `SWR-PRG-10` |
| `POST` | `/api/manual` | Enter manual mode at a target temperature | `SWR-CTL-14` |
| `POST` | `/api/fault/ack` | Acknowledge a latched fault | `SWR-SAF-17` |
| `POST` | `/api/tune` | Start autotune `{setpoint, amplitude, hysteresis}` | `SWR-TUN-03` |
| `GET` | `/api/tune` | Phase, cycles, `Ku`, `Tu`, candidate gain sets | `SWR-TUN-10` |
| `POST` | `/api/tune/accept` `cancel` | Accept a rule's gains / cancel | `SWR-TUN-09` |
| `GET` | `/api/runs` | Run records, newest first | `SWR-LOG-09` |
| `GET` | `/api/log` | `?run=&from=&to=&max_points=&format=json\|csv` | `SWR-LOG-10`, `SWR-WEB-18` |
| `DELETE` | `/api/log` | Erase all sample logs | `SWR-LOG-13` |
| `GET` | `/api/current` | Live RMS current, reference current, power, energy, wear counters | `SWR-CUR-07`, `SWR-CUR-13` |
| `POST` | `/api/current/calibrate` | One-point calibration against a reference reading | `SWR-CUR-06` |
| `GET` | `/api/storage` | Log and filesystem health | `SWR-LOG-15` |
| `GET` | `/api/net` | WiFi diagnostics | `SWR-NET-09` |
| | | **No firmware route.** The update path points outwards, §13.5 | `SWR-UPD-01`, `SWR-UPD-08` |

> **This table predates the read-only decision of 2026-10-06** and still lists
> the state-changing routes it removed. Every non-`GET` request now returns
> `403 read_only` (`SWR-WEB-26`), and the handlers are deleted from the image
> rather than disabled. Read the method column as "what the route would have
> been"; `kiln_web`'s API surface is the authority.

### 12.2 Request handling

Every handler declares a maximum body size and parses into a fixed buffer; there
is no unbounded accumulation and no allocation proportional to input
(`SWR-NFR-19`). Long responses, log queries, program lists, are streamed in
bounded chunks. Handlers never call into `kiln_core` directly; they post commands
to `kiln_app` and read the published snapshot (`SWA-16`), so no HTTP request can
delay or reorder a control cycle (`SWR-NFR-02`, `SWR-WEB-21`).

Authentication compares a salted hash of the password in constant time and
applies an increasing delay after repeated failures (`SWR-NFR-19`).

`SWR-WEB-26` makes the interface an observation surface: no route reachable over
the network can put heat into the kiln, write configuration or clear a latched
fault. The handlers for those routes are **deleted rather than disabled**: the
firmware cannot start a firing over HTTP because the code to do it is not in
the image, which is a stronger claim than a flag somebody could flip back. What
remains writable is program authoring, on the reasoning that a stored curve
cannot heat anything until it is started at the kiln; that is a *capability*
distinction, not a read/write one, and it is the reason the interface is not
literally read-only. Refusals are `403 read_only`, not `405`: the operation
does not exist here at any verb, and the message says where the control is.

### 12.3 Client

Plain ES modules, no framework, no build-time network access (`UR-CON-06`). Four
views: **Dashboard** (live values, chart, run controls), **Programs** (segment
editor with live curve preview), **History** (run list and chart), **Settings**
(generated from the config schema, plus network, tuning and OTA).

The chart is a self-contained canvas renderer in `web/chart.js`: two y-axes, the
measured trace plus the setpoint, optional duty and case series, zoom and pan on
the time axis, and a cursor readout (`SWR-WEB-06`, `SWR-WEB-07`, `SWR-WEB-10`). It
requests `max_points` matched to the canvas width, so a 24 h run arrives as
roughly 800 decimated points rather than 8 600 raw ones, which is how
`SWR-WEB-11` is met, and why `SWR-LOG-11` insists that decimation preserve
extrema. During a run, the planned remainder is fetched from
`/api/programs/{id}/preview` and drawn as a dashed continuation of the actual
trace (`SWR-WEB-08`). [`OQ-04`](03_software_req.sdoc) is hereby
resolved in favour of a hand-written renderer: the requirement is two axes and a
handful of series, and this keeps the asset budget and the licence audit trivial.

The SSE connection drives every live value; on disconnect the UI marks values
stale and reconnects with backoff rather than showing old data as current
(`SWR-WEB-25`).

**How the stream is served, and why not from the handler.** `esp_http_server`
runs one task and serialises handlers on it, so a handler that looped pushing a
frame a second would hold that task for as long as a browser tab stayed open:
the other sockets would never be served again, and the kiln would appear to
hang the moment somebody left a dashboard open and then tried to load the log.

So `/api/events` does not stream from its handler. It hands the socket to the
server's async machinery (`httpd_req_async_handler_begin`), parks the request in
a two-slot table and returns, which releases the server task immediately. One
task at priority 3 -- below the server's 4, far below control and safety --
pushes to every parked subscriber once a second, with an SSE comment frame every
fifteen pushes to keep an idle proxy or a phone's radio from dropping a stream
that is working.

Two subscribers, not four: a stream holds its socket indefinitely, so letting
every socket become one would leave nothing for the page, the log or an update
check. Two is a dashboard on a phone and one on a laptop. A third is refused
with `503` and `Retry-After` rather than queued, because a client that is told
to come back does and one left hanging does not. The socket count is six rather
than four for the same reason: `SWR-WEB-21` counts *clients*, and a client with
a dashboard open holds one socket parked on the stream and needs another to
fetch anything else.

The framing is in `kiln_web/api` rather than in the transport, because it is the
part of SSE that can be got wrong and the transport cannot be host-tested. A
frame that does not fit its buffer is not written at all, and a payload
containing a newline is refused: a newline inside a data field is SSE's own way
of writing a multi-line payload, so half a frame or a stray newline does not
fail visibly, it moves the frame boundary into the middle of a JSON document and
every frame after it is misread. The development harness in
`firmware/controller/host/webhost` uses the same framing function, so the format
the browser is tested against is the format the device sends.

### 12.4 Asset budget

| Asset | Budget (gzipped) | Measured 2026-10-09 |
|---|---|---|
| `index.html` | 4 kB | 2.2 kB |
| `app.css` | 6 kB | 3.6 kB |
| `app.js` (views, SSE, API client) | 24 kB | 8.6 kB |
| `chart.js` | 10 kB | 4.2 kB |
| Font | 0, system font stack only | 0 |
| **Total** | **44 kB** | **18.6 kB** |

Measured for the first time when the assets were embedded, and they pass with
room. The four are gzipped at build time by `kiln_web`'s CMakeLists and linked
in as binary data, so the hardware image carries them at 908 kB, 56 % of the
OTA slot still free.

They are served **still compressed**, with `Content-Encoding: gzip`: every
browser that can run this interface can inflate it, and inflating on the device
would cost a window buffer per request on the processor that is also running a
kiln.

The simulated image is **unchanged at 246 kB**, and that is the linker rather
than a special case. `CONFIG_KILN_PLANT_SIM` compiles out the call that starts
the server, nothing then references the asset table, and `--gc-sections` drops
the blobs with it. The configuration that cannot serve the interface does not
carry it.
| **Total** | **≤ 48 kB** embedded in the image (`SWA-11`) |

## 13. Cross-cutting concerns

### 13.1 Error handling

Core functions return an explicit result enum; nothing is silently ignored
(`SWR-NFR-17`). The three classes are distinct: a **fault** is a safety condition
and latches ([§8](#8-safety-subsystem)); a **warning** is a degradation that
does not stop a firing (log store unavailable, display gone, WiFi down) and is
published and displayed but not latched; an **error** is a rejected request,
returned to its caller with a reason and never escalated to the plant.

A failure in the HMI, log store, network or web server can never stop a firing , 
those subsystems are downstream of the control path by construction
(`SWR-HMI-14`, `SWR-LOG-14`, `SWR-NET-07`).

### 13.2 Diagnostic logging

ESP-IDF `ESP_LOGx` at a configurable level, over USB-Serial-JTAG only, never on
a pin shared with a peripheral (`SWR-NFR-24`). Operationally significant events go
to the *event* log in flash, not to the console, so a post-mortem needs no
attached terminal. Optional UDP syslog mirrors events for `SWR-NET-10`.

### 13.3 Timing budget

Measured and reported by the instrumented build (`SWR-TST-18`).

| Path | Budget | Requirement |
|---|---|---|
| `acquire` cycle, two SPI conversions + filtering | ≤ 20 ms | `SWR-ACQ-03` |
| `control` cycle, setpoint + PID + publish | ≤ 2 ms | `SWR-NFR-01` |
| `safety` cycle, all rules | ≤ 2 ms | `SWR-NFR-03` |
| `heat_window` timer callback | ≤ 50 µs | `SWA-07` |
| Fault detection → duty 0 | ≤ 110 ms | `SWR-NFR-04` |
| Fault detection → contactor open | ≤ 1 s | `SWR-NFR-04` |
| Reset → measuring, heat safely off | ≤ 3 s | `SWR-NFR-09` |
| Control period jitter | ≤ ±5 % | `SWR-NFR-01` |

### 13.4 Resource budget

| Item | Budget |
|---|---|
| Task stacks, total | 29 kB |
| `kiln_core` static state | ≤ 8 kB |
| Log queue (64 × 16 B) | 1 kB |
| Display framebuffer | 1 kB |
| HTTP server + 4 sessions | ≤ 40 kB |
| Free internal heap, minimum | ≥ 48 kB (`SWR-NFR-12`) |
| Application image | ≤ 2 MB (`SWR-NFR-13`) |

### 13.5 Firmware update

The path decided on 2026-10-09 (`SWR-UPD-09` to `SWR-UPD-16`, `OQ-08`), and the
reasoning for its direction is in
[`security.md` §6.2](security.md#62-the-update-path-and-why-it-points-outwards).
The device **pulls**; the operator at the display **authorises**; the web
interface stays read-only and gains no exception.

```mermaid
sequenceDiagram
    participant UP as update task (core 0)
    participant SVC as update.bitcrushtesting.com
    participant APP as kiln_app
    participant HMI as display + encoder
    UP->>SVC: GET /safekiln/stable.json (daily, jittered)
    SVC-->>UP: manifest + detached signature
    UP->>UP: verify signature, parse, compare semver locally
    UP->>APP: available(version, security?)
    APP->>HMI: announce, not over a firing screen
    HMI->>APP: operator confirms (deliberate act)
    APP->>UP: fetch and install
    UP->>SVC: GET the image
    UP->>UP: stream into the inactive slot, digest + image signature
    UP->>APP: ready, restart to apply
    HMI->>APP: operator confirms the restart
    APP->>UP: set boot partition, reboot
    UP->>UP: next boot: pending-verify until the self-checks pass
```

Five properties of this that are decisions rather than details:

1. **The manifest is static and the comparison is local** (`SWR-UPD-10`). One
   file for every device, no query string, no identifier, no installed version
   in the request. That is what keeps the check out of the telemetry category
   (`SEC-06`) and it constrains the service as much as the client: a per-device
   URL would break it.
2. **Authenticity does not come from the connection** (`SWR-UPD-11`). The
   manifest signature is checked against a public key in the image, from an
   offline key that is **not** the secure boot key, and the image is checked
   against both the manifest digest and its own appended signature. HTTPS is
   required and assumed to fail eventually.
3. **The update task lives on core 0**, with networking, and holds no authority
   over heat (`SWA-15`, `SWA-04`). It posts an availability fact to `kiln_app`
   and waits; it never reaches into `kiln_core`.
4. **Nothing installs without a local act** (`SWR-UPD-12`, `SWR-HMI-16`), and
   the restart is a second one. `SWR-UPD-04`'s refusal during a run or autotune
   is enforced in `kiln_app`, where the state machine lives, not in the port.
5. **Rollback is cancelled late** (`SWR-UPD-15`). The first boot of a new image
   stays pending-verify until the supervisor link, both thermocouples, the
   configuration and the display have all proved themselves in the running
   system. `confirm_running()` in start-up code would make
   `SWR-UPD-02` decoration.

#### The manifest

One static file per channel, served at `<update.url>/<channel>.json`, built and
signed by [`tools/update-manifest.py`](../tools/update-manifest.py). It is an
envelope whose `payload` is the base64 of the **exact bytes that were signed**:

```json
{
  "alg": "RSA3072-PSS-SHA256",
  "key_id": "3f2a91c4",
  "payload": "eyJzY2hlbWEiOiAxLCAicHJvZHVjdCI6ICJzYWZla2lsbiIsIC4uLg==",
  "sig": "<base64 of 384 bytes>"
}
```

Signing the bytes rather than the object is the decision worth defending. A
device that re-serialised the parsed JSON to check a signature would have to
agree with the signing tool about key order, spacing and number formatting for
ever, and the usual failure is a verifier that passes on every manifest it was
tested with and rejects the one that matters. Here the device base64-decodes,
verifies over those bytes, and parses afterwards, so canonicalisation is nobody's
problem.

The payload, once decoded:

| Field | Meaning |
|---|---|
| `schema` | `1`. A later format change is detectable rather than confusing |
| `product` | `safekiln` |
| `channel` | `stable`, matching the filename |
| `target` | `esp32s3`, cross-checked by the tool against the image's own chip id |
| `version` | a **release** semantic version, `1.4.2`. Never `1.4.2+7.gabc1234.dirty`: `SWR-UPD-06` allows build metadata on a build that is not on a tag, and `SWR-UPD-13` compares versions, so publishing one would put a non-release in a channel |
| `released` | ISO date, for the operator and the advisory, not for logic |
| `security` | `true` for a security release (`SWR-UPD-16`), which then requires `advisory` |
| `advisory` | relative path to the advisory |
| `image` | relative path to the image |
| `size`, `sha256` | checked before the image is marked bootable (`SWR-UPD-11`) |

**Every path is relative**, resolved against the manifest's own directory, and
the tool refuses an absolute one. `update.url` exists so a site can mirror the
service rather than let the controller out to the internet (`SRR-13`), and with
relative paths a mirror is a directory copy; one absolute URL would send every
mirrored device back to the origin.

What the manifest deliberately does **not** carry is release notes. The display
is 128×64 pixels and `SWR-HMI-16` shows a version and whether it is a security
release; a field only a browser could render would become the reason somebody
adds a browser. The advisory is a URL for a human on another device.

The signing key is **RSA-3072, PSS, SHA-256**, matching the scheme the ESP32-S3
ROM already verifies for secure boot so the release process has one key size to
think about. It is **not** the secure boot key (`SRR-12`): that one decides what
a board will *boot* and its digest is burnt into eFuses, this one decides what a
board will be *offered*. The public half is compiled in as DER
SubjectPublicKeyInfo, generated by `update-manifest.py pubkey --header`, so
`mbedtls_pk_parse_public_key` can take it without a PEM decoder.

The partition table needs no change: `otadata`, `ota_0` and `ota_1` are already
there (§10.1), sized at 2 MB against the ≤ 2 MB image budget of §13.4. What is
unbuilt is the client, the verifier, the screen and the discipline in point 5,
and all of it waits on the HTTP stack that §12 still describes as unimplemented.

## 14. Build and test architecture

This section is the implementation of [requirements §7](03_software_req.sdoc).

### 14.1 Repository layout

```
safekiln/
├── LICENSE                      GPL-3.0
├── README.md
├── strictdoc.toml               StrictDoc project config
├── docs/
│   ├── 03_software_req.sdoc        the requirements (StrictDoc)
│   ├── 04_software_arch.sdoc        the 21 architecture decisions (StrictDoc)
│   └── architecture.md          this document
├── firmware/controller/
│   ├── CMakeLists.txt
│   ├── sdkconfig.defaults
│   ├── partitions.csv
│   ├── main/                    app_main: composition root only
│   ├── components/
│   │   ├── kiln_core/           pure logic (SWA-01), no IDF headers
│   │   ├── kiln_ports/          interface headers only
│   │   ├── kiln_hal_esp32s3/    adapters: max31856, ssd1306, encoder,
│   │   │                        heat output, logstore, nvs, clock
│   │   ├── kiln_app/            tasks, run controller, event bus, settings
│   │   ├── kiln_web/            httpd, handlers, embedded gzipped assets
│   │   └── kiln_sim/            plant simulator (SWR-TST-11)
│   └── test/
│       ├── host/                CMake, no IDF: unit + integration + fuzz
│       └── target/              Unity + pytest-embedded
├── web/                         UI sources; build output vendored into kiln_web
├── hardware/                    schematic, PCB, pin map
├── housing/                     enclosure
└── tools/
    ├── logdump                  decode a log partition dump to CSV
    ├── trace                    requirement traceability checker (SWR-TST-22)
    └── layercheck               dependency-rule enforcement (SWR-TST-07)
```

### 14.2 Dual-target build

`kiln_core`, `kiln_ports` and `kiln_sim` carry both an ESP-IDF
`idf_component_register` and a plain `add_library` path, selected by whether
`ESP_PLATFORM` is defined. The host build is an ordinary CMake project:

```
cmake -B build-host -S firmware/controller/test/host -DENABLE_COVERAGE=ON -DENABLE_ASAN=ON
cmake --build build-host && ctest --test-dir build-host
```

Because the core has no IDF dependency, host tests build in seconds and run
under a debugger, ASan and UBSan (`SWR-TST-20`), with gcov coverage (`SWR-TST-19`).

### 14.3 Plant simulator

First-order-plus-dead-time (`SYS-ASM-01`), integrated at the test's own step size:

```
T[n+1] = T[n] + dt/tau * (K * u_delayed(n) + T_ambient - T[n]) + noise(seed)
```

Configurable `K`, `tau`, dead time, ambient, heat-loss nonlinearity at high
temperature, and sensor noise. The simulator also produces a heater **current**
consistent with the commanded output state and the injected electrical faults
(`SWR-TST-27`), so the current rules are driven by the same plant as the thermal ones
and a fault shows up in both channels exactly as it would on a real kiln. Deterministic from a seed, so a failure replays
exactly (`SWR-TST-12`). Injectable faults, each mapping to a safety rule:

| Injection | Exercises |
|---|---|
| Element open / partially failed | `SWR-SAF-07`, `SWR-SAF-26`, `SWR-SAF-28` |
| Relay fail-on (current with duty 0) | `SWR-SAF-25` |
| Relay fail-off (no current with duty > 0) | `SWR-SAF-26` |
| Welded contactor (current persists after contactor opened) | `SWR-SAF-27` |
| Over-current | `SWR-SAF-29` |
| Current transformer disconnected | `SWR-CUR-11`, `SWR-CUR-12` |
| SSR shorted (heats at 0 % duty) | `SWR-SAF-08`, `SWR-SAF-25` |
| TC open / short / out of range | `SWR-SAF-04` |
| TC reversed | `SWR-SAF-05` |
| TC stuck | `SWR-SAF-06` |
| TC drift | `SWR-ACQ-08`, `SWR-SAF-12` |
| Lid opened mid-firing | `SWR-SAF-07`, `SWR-CTL-11` |
| Enclosure heating | `SWR-SAF-11` |
| Power loss at an arbitrary instant | `SWR-RUN-08`, `SWR-LOG-08` |
| Flash write failure | `SWR-LOG-14` |
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

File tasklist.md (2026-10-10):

<!--
SPDX-FileCopyrightText: 2026 Bitcrush Testing
SPDX-License-Identifier: GPL-3.0-or-later
-->

# Safe Kiln Controller Task List

**Outstanding work only.** An item leaves this file when it is done; what was
done and why is in the commit that did it, not here. Checked against
[`docs/03_software_req.sdoc`](docs/03_software_req.sdoc),
[`docs/architecture.md`](docs/architecture.md), [`docs/safety.md`](docs/safety.md)
and [`docs/security.md`](docs/security.md).

Item IDs are stable and referenced from commit messages, so a letter is never
reused: gaps in the numbering are items that have been closed.

| | Meaning |
|---|---|
| **P1** | Safety-relevant or blocking. Do before the next board revision, and before any firing. |
| **P2** | Required for a release that claims the requirements are met. |
| **P3** | Correctness polish, consistency, cleanup. |
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

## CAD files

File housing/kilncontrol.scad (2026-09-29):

// SPDX-FileCopyrightText: 2026 Bitcrush Testing
// SPDX-License-Identifier: GPL-3.0-or-later
//
// KilnControl -- enclosure
//
// Parametric two-part housing: a base holding the controller PCB and the
// mains switching relay in segregated bays, and a lid carrying the display
// and encoder.
//
// Requires BOSL2, vendored as a submodule at housing/libraries/BOSL2.
//   git submodule update --init --recursive
//
// Render:
//   openscad -D 'part="base"' -o base.stl kilncontrol.scad
//   openscad -D 'part="lid"'  -o lid.stl  kilncontrol.scad
//   openscad -D 'part="all"'  -o all.stl  kilncontrol.scad   (assembled preview)

include <libraries/BOSL2/std.scad>

/* [What to render] */
// base | lid | all
part = "all";

/* [PCB] ------------------------------------------------------------------ */
// Matches the KiCad board outline: 100 x 100 mm, M3 at 4.5 mm inset.
pcb_x          = 100;
pcb_y          = 100;
pcb_t          = 1.6;
pcb_hole_inset = 4.5;
pcb_hole_d     = 3.2;   // clearance hole in the board
pcb_gap        = 1.0;   // clearance around the board inside its bay

// Height of the tallest thing standing on the PCB. The EC11 encoder body and
// the 5.08 mm screw terminals set this; the shaft passes through the lid.
pcb_tall_part  = 24;

/* [Relay: Songle SLA-05VDC-SL-C, LCSC C87367] ---------------------------- */
// Plan size is from the LCSC package field (32 x 27.6 mm).
// TODO verify height against the datasheet before printing; 20.6 is the
// published figure for the SLA series but has not been measured here.
relay_l   = 32.0;
relay_w   = 27.6;
relay_h   = 20.6;
relay_gap = 1.5;    // clearance around the relay body

/* [Shell] ---------------------------------------------------------------- */
wall        = 2.4;   // side walls
floor_t     = 2.4;
lid_t       = 2.4;
standoff_h  = 8.0;   // clearance under the PCB for through-hole leads
corner_r    = 3.0;
boss_d      = 7.0;   // lid screw boss outer diameter
boss_hole_d = 2.5;   // pilot for an M3 self-tapping screw
insert_d    = 4.2;   // set >0 to bore for M3 heat-set inserts instead
insert_h    = 5.0;
use_inserts = true;

/* [Ventilation] ---------------------------------------------------------- */
// SR-11 trips on enclosure over-temperature, so the box has to actually
// breathe. Slots are on the side walls, not the top, to keep kiln-room dust
// and debris from dropping straight in.
vent            = true;
vent_slot_w     = 3.0;
vent_slot_h     = 14.0;
vent_slot_pitch = 7.0;
vent_count      = 6;

/* [Panel cutouts] -------------------------------------------------------- */
// Positions are relative to the PCB origin (its lower-left corner) and are
// PLACEHOLDERS until the KiCad placement is done -- the board has no
// footprints on it yet, so these cannot be final. Set panel_cutouts=false to
// print a blank lid and drill later.
panel_cutouts = true;

oled_win_x  = 30;    // window for the 128x64 OLED
oled_win_y  = 60;
oled_win_w  = 27.0;  // active area of a typical 1.3" SSD1306/SH1106 module
oled_win_h  = 15.0;

enc_x       = 78;    // encoder shaft
enc_y       = 30;
enc_shaft_d = 7.5;   // 6 mm shaft + clearance for the threaded bushing
enc_nut_d   = 10.0;  // recess for the mounting nut
enc_nut_h   = 1.2;

// Sound port over the on-board buzzer (BZ1, TMB12A05, 12 mm dia). A buzzer
// sealed inside the box is heavily muffled, and SR-20 depends on the operator
// actually hearing it, so the lid is perforated above it.
buzz_x        = 45;    // centre of BZ1, relative to the PCB origin
buzz_y        = 15;
buzz_port_d   = 11.0;  // diameter of the perforated area
buzz_hole_d   = 1.6;   // individual hole
buzz_hole_ring= 7;     // holes in the outer ring

usb_x       = 0;     // USB-C access on the -X wall, centred on this Y
usb_y       = 20;
usb_w       = 11.0;
usb_h       = 5.5;

/* [Cable entry] ---------------------------------------------------------- */
// Field wiring (power, thermocouples, SSR, contactor coil, buzzer, CT) leaves
// through one wall so it can be strain-relieved as a single loom.
cable_slot   = true;
cable_slot_w = 60;
cable_slot_h = 12;

/* ======================================================================== */
/* Derived                                                                  */
/* ======================================================================== */

pcb_bay_x = pcb_x + 2*pcb_gap;
pcb_bay_y = pcb_y + 2*pcb_gap;

relay_bay_x = relay_l + 2*relay_gap;
relay_bay_y = relay_w + 2*relay_gap;

// Barrier between the SELV control bay and the relay, whose terminals carry
// mains. The controller PCB itself is entirely SELV -- the only mains on this
// product is at the relay and inside the kiln.
barrier_t = wall;

inner_x = pcb_bay_x + barrier_t + relay_bay_x;
inner_y = max(pcb_bay_y, relay_bay_y);
inner_z = standoff_h + pcb_t + pcb_tall_part;

outer_x = inner_x + 2*wall;
outer_y = inner_y + 2*wall;
outer_z = floor_t + inner_z;

// Origin of the PCB (its lower-left corner) in base-local coordinates, where
// (0,0) is the centre of the outer footprint.
pcb_ox = -inner_x/2 + pcb_gap;
pcb_oy = -inner_y/2 + pcb_gap;

// The four PCB mounting points, as offsets from the PCB origin.
pcb_holes = [
    [pcb_hole_inset,          pcb_hole_inset],
    [pcb_x - pcb_hole_inset,  pcb_hole_inset],
    [pcb_hole_inset,          pcb_y - pcb_hole_inset],
    [pcb_x - pcb_hole_inset,  pcb_y - pcb_hole_inset],
];

// Lid screw bosses, inset from each corner of the inner cavity.
boss_inset = boss_d/2 + 0.6;
boss_pos = [
    [-inner_x/2 + boss_inset, -inner_y/2 + boss_inset],
    [ inner_x/2 - boss_inset, -inner_y/2 + boss_inset],
    [-inner_x/2 + boss_inset,  inner_y/2 - boss_inset],
    [ inner_x/2 - boss_inset,  inner_y/2 - boss_inset],
];

$fn = 48;

/* ======================================================================== */
/* Base                                                                     */
/* ======================================================================== */

module standoffs() {
    for (h = pcb_holes)
        translate([pcb_ox + h[0], pcb_oy + h[1], floor_t])
            difference() {
                cyl(h = standoff_h, d = pcb_hole_d + 3.2, anchor = BOTTOM);
                // Pilot for an M3 self-tapping screw into the standoff.
                down(0.01) cyl(h = standoff_h + 0.02, d = 2.5, anchor = BOTTOM);
            }
}

module lid_bosses() {
    for (p = boss_pos)
        translate([p[0], p[1], floor_t])
            difference() {
                cyl(h = inner_z, d = boss_d, anchor = BOTTOM);
                up(inner_z - (use_inserts ? insert_h : inner_z) + 0.01)
                    cyl(h = (use_inserts ? insert_h : inner_z) + 0.02,
                        d  = (use_inserts ? insert_d : boss_hole_d),
                        anchor = BOTTOM);
                // Always leave a through pilot so a longer screw can be used.
                down(0.01) cyl(h = inner_z + 0.02, d = boss_hole_d, anchor = BOTTOM);
            }
}

module relay_pocket() {
    // A shallow rib pocket that locates the relay body and stops it sliding.
    rx = inner_x/2 - relay_bay_x/2;
    translate([rx, 0, floor_t])
        difference() {
            cuboid([relay_bay_x, relay_bay_y, 3], anchor = BOTTOM);
            down(0.01)
                cuboid([relay_l + 0.6, relay_w + 0.6, 3.02], anchor = BOTTOM);
        }
}

module barrier_wall() {
    // Segregates the relay (mains) from the control bay (SELV).
    bx = -inner_x/2 + pcb_bay_x + barrier_t/2;
    translate([bx, 0, floor_t])
        cuboid([barrier_t, inner_y, inner_z], anchor = BOTTOM);
}

module vent_slots(y_face) {
    // Cut through a Y wall at +/- inner_y/2.
    span = (vent_count - 1) * vent_slot_pitch;
    for (i = [0 : vent_count - 1])
        translate([-span/2 + i*vent_slot_pitch,
                   y_face * (inner_y/2 + wall/2),
                   floor_t + inner_z/2])
            cuboid([vent_slot_w, wall * 3, vent_slot_h], anchor = CENTER,
                   rounding = vent_slot_w/2 - 0.01, edges = "Y");
}

module base() {
    difference() {
        union() {
            // Outer shell with an open top.
            difference() {
                cuboid([outer_x, outer_y, outer_z], anchor = BOTTOM,
                       rounding = corner_r, edges = "Z");
                up(floor_t)
                    cuboid([inner_x, inner_y, inner_z + 0.02], anchor = BOTTOM,
                           rounding = max(corner_r - wall, 0.1), edges = "Z");
            }
            standoffs();
            lid_bosses();
            relay_pocket();
            barrier_wall();
        }

        // Ventilation on both long walls.
        if (vent) { vent_slots(+1); vent_slots(-1); }

        // Field wiring exit on the -X wall.
        if (cable_slot)
            translate([-outer_x/2, 0, floor_t + standoff_h + pcb_t + cable_slot_h/2])
                cuboid([wall * 3, cable_slot_w, cable_slot_h], anchor = CENTER,
                       rounding = 2, edges = "X");
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

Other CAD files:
housing/safekiln.scad

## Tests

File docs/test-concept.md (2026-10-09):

<!--
SPDX-FileCopyrightText: 2026 Bitcrush Testing
SPDX-License-Identifier: GPL-3.0-or-later
-->

# Test concept

How this product is verified, at four levels, and what each one can and cannot
prove. The testability requirements it answers are `SWR-TST-01` to `SWR-TST-28` in
[`03_software_req.sdoc`](03_software_req.sdoc); section 10 states plainly which of
them are met today and which are not.

The organising idea is that each level exists to prove something the level
below it cannot, and that saying so is more useful than counting tests. A
suite of 431 passing tests that has never seen a thermocouple is not evidence
that the kiln will stop heating when the probe falls out.

## 1. The levels

| | Level | Runs on | Proves | Cannot prove |
|---|---|---|---|---|
| **L1** | Unit | Development host, seconds | Each rule and algorithm against its requirement, including arithmetic nobody can see by reading | That the components are wired together |
| **L2** | Integration | Development host, in process | Components against each other and against a plant model: closed-loop control, persistence across power cuts, the API's answers | That the real image runs, or that any hardware works |
| **L3** | System | QEMU, and a host harness with real sockets | The real firmware image booting and firing; the HTTP interface as a client actually sees it | Anything analogue, anything about timing on real silicon, anything about the hardware safety chain |
| **L4** | HIL | The board, with a fixture | The adapters, the electrical detections, timing under load, and the hardware interlocks that are the whole safety case | Nothing below it, which is why it is last and not instead |

Two independent firmwares are tested, not one: the ESP32 application and the
STM32 supervisor of [`SWA-22`](04_software_arch.sdoc). They share no product code,
so they have separate unit suites, and they first meet each other at L4.

## 2. L1, unit tests

**Where:** `firmware/controller/test/host/unit/` (302 tests) and
`firmware/supervisor/test/host/` (33 tests). Plain CMake, no ESP-IDF, no ARM toolchain,
about four seconds for the lot.

This level is cheap because of `SWA-01` to `SWA-03`, and those decisions exist
mostly to make it cheap: logic components take an explicit context (`SWR-TST-04`),
reach hardware only through port interfaces (`SWR-TST-02`), and never read a clock
(`SWR-TST-03`). A 168-hour firing, a 15-minute runaway timer and a two-hour autotune
are therefore all exercised in milliseconds of wall time, because time is an
argument.

What belongs here: every safety rule, the PID, the setpoint generator, program
validation, the log codec, the configuration model, the JSON parser, the trip
logic and wire format of the supervisor. What does not: anything needing two
components to be connected.

Run under ASan and UBSan as well as plain (`SWR-TST-20`), because an arithmetic
rule that is correct and also reads past an array is not correct.

**The supervisor is held to a different coverage bar, and the reason is
specific.** Its permit decision is a five-term conjunction:

```c
permit = selftest_ok && !tripped && any_valid(in) && !disagreeing(in)
      && fault_bits == 0 && effective_q7(in) <= SUP_OVERTEMP;
```

One test with every term true and one with every term false gives 100 % line
*and* 100 % branch coverage of that line, and demonstrates almost nothing: not
that a missing reading alone withholds heat, nor that a reported fault alone
does. `SWR-TST-29` therefore requires **80 % modified condition/decision coverage**
of the trip logic and the wire format, which is the criterion that makes each
condition prove it can change the outcome by itself. A five-term decision needs
at least six cases that differ in the right way.

gcov cannot measure MC/DC, so this uses Clang's `-fcoverage-mcdc` rather than
the gcovr that enforces `kiln_core`'s line floor. `tools/mcdc.sh` measures it,
fails below the floor, and on failure prints the exact condition pairs that are
uncovered, because a coverage gate that only reports a percentage is a gate
nobody can act on.

It currently sits at **100 %**, and getting there found two real gaps that line
coverage could not see: `sup_flags` had never been called with its *second*
argument null, and `sup_decode`'s resynchronisation path had never run for a
caller passing `nullptr` for the skip count. Both are argument guards where only
half the guard had ever been exercised.

This bar applies to the supervisor alone. It is about 120 lines, it is the only
component where failing to evaluate a condition means heat that should have
stopped, and its whole justification is that it can be read in full. Holding the
other 30 000 lines to the same criterion would be a different and much larger
argument.

The fuzz suite (`firmware/controller/test/host/fuzz/`) sits here too. It feeds the log
record decoder deliberately hostile bytes, on the argument that the one thing
reading data written by an earlier firmware version should survive is a record
that makes no sense.

## 3. L2, integration tests

**Where:** `firmware/controller/test/host/integration/` (92 tests), in one process,
against the plant simulator and the fake ports of `kiln_hal_host`.

This is where the real control, setpoint, safety and autotune code runs
closed-loop against a thermal model (`SWR-TST-14`), and where the properties that
only emerge from interaction get tested:

- **A firing, end to end.** Programs execute, setpoints advance, hold-back
  suspends them, dwells complete, the log fills.
- **Power loss.** The fake flash can be told to lose power at the *n*th write,
  which is how `SWA-09`'s claim that the log is the recovery journal gets
  tested rather than asserted.
- **The API's answers**, route by route, without a socket in sight.
- **Fault injection.** `kiln_sim` carries the `KILN_INJ_*` faults of `SWR-TST-11`
  and `SWR-TST-27`: open element, shorted SSR, welded contactor, disconnected CT,
  reversed or stuck thermocouple, open lid. `SWR-TST-09` requires every fault
  condition to be reachable without hardware, and this is where that is
  satisfied.

The simulator is deterministic from a seed (`SWR-TST-12`), so a failure can be
replayed rather than reproduced.

## 4. L3, system tests

The real image, through its real external interfaces. Two harnesses, because
no single one has both properties that matter.

**QEMU** (`tools/run-qemu.sh`, and the `qemu-smoke` CI job) boots the actual
`safekiln.bin` built by the actual toolchain, on the target's scheduler and
FPU, and fires a program. It is not a substitute for L2, which covers far more
in far less time. What it adds is the one thing L2 cannot: that the image
*works as an image*. It currently fires to 190 °C through segment 2 of 5 with
no fault latched.

**`host/webhost`** runs the real firmware logic behind a real POSIX socket
server with the plant simulated and time accelerated. This is where the HTTP
interface is exercised as a client sees it (`SWR-TST-16`): URI splitting, chunked
log streaming, the four-session limit, a slow client holding a buffer.
Tasklist `P4` records that this is not yet done; the harness exists and the
tests do not.

System tests are the right home for requirements expressed in terms of what an
operator or a client can observe, which is most of `FR-WEB`, `FR-RUN`,
`FR-LOG` and `FR-CFG`.

## 5. L4, hardware in the loop

### 5.1 Why this level is not optional

Everything above it shares one blind spot: it proves things about *software*.
The central claims of this product are not about software.

- That the supervisor's series element opens the contactor coil.
- That a hung ESP32 stops toggling `HEAT_EN` and the charge pump drops the
  contactor within about a second (`SWA-05`).
- That the lid switch breaks the coil in hardware with no firmware involved
  (`SYS-HW-21`).
- That a thermocouple pulled out of its terminals is detected as an open
  circuit by a real MAX31856, and that its `~FAULT` output asserts.
- That `SWR-SAF-27` can tell a shorted SSR from a welded contactor by dropping the
  contactor and re-measuring real current.
- That the loop meets `SWR-NFR-01` to `SWR-NFR-04` on real silicon under HTTP and WiFi
  load (`SWR-TST-18`).

None of those is testable in simulation, and all of them are load-bearing.
`SWR-TST-17` requires a documented HIL procedure with a low-power resistive load
and a thermocouple simulator; `SWR-TST-28` requires the jig to present a known
current and emulate a welded contactor. This section is that design.

### 5.2 The fixture, in one idea

**The fixture is a plant simulator with real analogue outputs, and it runs the
same plant model the host tests run.**

That is the whole architecture. `kiln_sim` already exists, already models
temperature *and* current, already carries the `KILN_INJ_*` fault injections,
and is already deterministic from a seed. Rather than writing a second plant
model that will disagree with the first, the fixture runs that one.

The consequence is worth stating: an L4 scenario can be the *same* scenario as
an L2 test, with the same seed and the same expected outcome. When they
disagree, the difference is isolated to the adapters, the analogue front ends
and the electricals, which is exactly and only what L4 is for.

```mermaid
flowchart LR
    subgraph host["Host PC"]
        SIM["kiln_sim<br/>plant model + fault injection"]
        TEST["test scripts<br/>same language as L2"]
    end
    subgraph jig["I/O board"]
        DAC["16-bit DAC<br/>+ 1:40 divider"]
        RLY["fault relays"]
        CUR["current source<br/>+ load bank"]
        TS["timestamping<br/>capture"]
    end
    subgraph dut["Board under test"]
        SUP["STM32<br/>supervisor"]
        ESP["ESP32-S3"]
    end
    TEST --> SIM
    SIM <-- "USB serial, 10 Hz" --> jig
    DAC -- "thermocouple EMF" --> SUP
    RLY -- "open / short / reverse" --> SUP
    CUR -- "real AC current" --> ESP
    SUP -- "UART frames" --> TS
    ESP -- "SSR, HEAT_EN, COIL_DRV, alarm" --> TS
```

The split is deliberate: the **model runs on the host**, so it is the same code
and the test scripts are the same language as L2; the **I/O board is close to
dumb**, but does its own hardware timestamping, because USB latency is fine for
a 10 Hz thermal model and useless for measuring a 10 ms SSR window.

### 5.3 Simulating the thermocouple

The hard part, and the part with a subtlety that is easy to get wrong.

**The device adds cold-junction compensation, so the fixture must subtract
it.** The MAX31856 reports a temperature derived from the EMF at its terminals
*plus* the EMF corresponding to its own cold-junction temperature. To make it
read `T_target`, the fixture must present

```
EMF = f(T_target) - f(T_cj)
```

where `f` is the type K polynomial and `T_cj` is the temperature of the chip,
which drifts with the enclosure. A fixture that ignores this reads correctly in
a cold lab and wrongly after an hour of firing.

The loop is already closed for us: **the supervisor reports `cj_c` in every
frame**, ten times a second, because the wire format carries it. The fixture
reads the UART it is already monitoring and computes the EMF it needs. No extra
sensor, no calibration against ambient, and the compensation tracks whatever
the board is actually doing.

**Resolution.** Type K is about 41 µV/°C over the range that matters, so 0.1 °C
is roughly 4 µV, and the full scale to 1350 °C is about 54 mV. A 16-bit DAC
spanning 0 to 2.5 V through a **1:40 divider** gives 0 to 62.5 mV at about
0.95 µV per step: 0.025 °C, which is finer than anything being tested.

**Accuracy, and why it needs less than it looks.** Almost every test here
verifies a *threshold crossing* or a *trend*, not an absolute reading. The
supervisor's backstop is tested by presenting 1340 °C and expecting no trip,
then 1360 °C and expecting one. With 20 °C of headroom either side, a fixture
good to ±2 °C absolute is ample. What it does need is **monotonicity and
repeatability**, plus a handful of calibrated points so the mapping is known
rather than assumed.

**The real error source is the fixture's own wiring.** Any dissimilar-metal
junction sitting in a temperature gradient generates microvolts, which is the
same unit the signal is in. The divider's low side must sit at the terminals,
its junctions must be paired and isothermal, and the connection to the DUT must
be the same alloy as the couple it replaces. This matters more than the DAC's
datasheet.

**Fault injection** is relays, not maths:

| Relay | Presents | Verifies |
|---|---|---|
| Open both leads | Open circuit | `SWR-SAF-04`, the MAX31856's open-circuit detect, `~FAULT` asserting |
| Short the pair | Shorted couple | `SWR-SAF-04` |
| Lead to 3V3 | Short to supply | `SWR-SAF-04`, front-end `OVUV` |
| Lead to ground | Short to ground | `SWR-SAF-04` |
| Swap the pair | Reversed polarity | `SWR-SAF-05`, which detects a reading that falls while heat is commanded |
| Hold the DAC | Stuck sensor | `SWR-SAF-06` |

Reversal is worth having as a relay rather than as a negative DAC output,
because reversing the *leads* is the failure that actually happens in the
field.

### 5.4 Simulating heater current

`SWR-TST-28` asks for a known current presented to the transformer, and the word
*transformer* is load-bearing: injecting a voltage into the CT's burden would
test the firmware's arithmetic while leaving the CT, the burden and the
anti-alias network untested.

So: a **low-power resistive load** on the SSR output with the clip-on CT around
that conductor (`SWR-TST-17`), and a separate, fixture-controlled **bypass path**
across it.

The bypass is the important part, because the fixture must be able to present
current the DUT did not ask for, and withhold current the DUT did ask for:

| Fixture does | DUT commands | Emulates | Verifies |
|---|---|---|---|
| Energise bypass | Off | Shorted SSR or welded contactor | `SWR-SAF-08`, `SWR-SAF-25` |
| Open the load | On | Open element | `SWR-SAF-26` |
| Partial load | On | Degraded element | `SWR-SAF-28` |
| Bypass, then watch the contactor drop | Off | Welded contactor | `SWR-SAF-27`'s discrimination sequence, which is the one `SWR-TST-28` names |
| Remove the CT | Either | CT unfitted or fallen off | `SWR-CUR-11`, `SWR-CUR-12` |

`SWR-SAF-27` is the reason this cannot be a signal generator. The discrimination
works by dropping the contactor and re-measuring: if current stops, the SSR was
shorted; if it persists, the contactor is welded. The fixture has to make a
real contactor's real contacts behave both ways.

### 5.5 Discrete inputs

The lid switch is a contact closure, so the fixture closes a contact. It must
be driven on **both** paths independently, because `SYS-HW-21` wires it to a
controller input *and* in series with the coil, and a fixture that drives only
the sense line would let a broken series contact pass. Opening the series path
with the sense line still closed is a specific, testable fault.

The encoder is quadrature plus a button: the fixture generates A/B sequences,
including the invalid transitions a worn encoder produces, and this is the one
place to settle tasklist `M5`, which records that the encoder's direction is
currently a guess.

The supervisor's clear button is a contact, and the fixture must be able to
hold it closed from power-on, because that is the stuck-line case the edge
triggering exists for.

### 5.6 What the fixture observes

Simulating the inputs is half of it. The assertions are on the outputs, with
timestamps.

| Observed | Resolution | For |
|---|---|---|
| `SSR1`, `SSR2` gates | microseconds | Window period, min-on and min-off (`SWR-CTL-07`, `SWR-CTL-08`, `SWA-07`) |
| `HEAT_EN` | microseconds | That it is a *square wave* and not a level, and its frequency (`SWA-05`) |
| `COIL_DRV`, and coil current | milliseconds | That the contactor actually closed, and when it dropped (`SWR-NFR-04`'s 1 s) |
| The supervisor's permit line | microseconds | Its trip latency, independently of what it reports |
| The supervisor's UART frames | per frame | Decoded with the same `sup_proto` codec the firmware uses, so the fixture cannot disagree about the format |
| Alarm output | milliseconds | `SWR-SAF-20` patterns |
| Current through the load | per mains cycle | The DUT's own measurement against the fixture's, which is the only way to check calibration |

Two of these deserve emphasis. **The supervisor's permit line is observed
separately from its reports**, because the whole point of `SWA-22` is that the
line does not depend on the firmware that describes it; a test that believed
the frame would be testing the wrong thing. And **the fixture links the real
`sup_proto.cpp`**, so a protocol change cannot make the fixture and the
firmware quietly disagree.

### 5.7 The independence test

One scenario matters more than any other at this level, and it exists only
here. Hold the ESP32 in reset, or run a build that deliberately hangs its
safety task, drive the chamber above 1350 °C with the DAC, and confirm the
contactor opens.

That is the single experiment that distinguishes this design from the one it
replaced. It cannot be done at any other level, and it should be run on every
hardware revision and recorded with the result.

### 5.8 Build or buy

The chamber channel's precision is the only part that is genuinely demanding.
A commercial thermocouple calibrator with a serial interface removes that risk
and costs more than the rest of the jig together.

The recommendation is to **build**, on the grounds in 5.3: the accuracy
required is modest because the tests are threshold tests, the cold-junction
loop closes itself from a frame the device already sends, and a fixture that
lives in the repository and is version-controlled alongside the firmware is
worth more than a more accurate instrument that lives in a drawer. One
calibrated reference is still wanted, once, to establish the mapping.

## 6. Verifying the architecture, not just the behaviour

[`04_software_arch.sdoc`](04_software_arch.sdoc) holds 22 decisions, and most of them
are **structural claims rather than behavioural ones**. They are verified by
assertions at build time, which is cheaper and much harder to fool than a
runtime test.

| How | Decisions |
|---|---|
| Static: grep, AST, `nm`, `static_assert`, link | `SWA-01`, `SWA-02`, `SWA-03`, `SWA-08`, `SWA-10`, `SWA-11`, `SWA-13`, `SWA-14`, `SWA-16`, `SWA-18`, `SWA-19`, `SWA-20`, `SWA-21` |
| Runtime, in process (L2) | `SWA-04`, `SWA-06`, `SWA-07`, `SWA-09`, `SWA-12`, `SWA-17` |
| HIL only (L4) | `SWA-05`, `SWA-15`, `SWA-22` |
| Nothing to assert | `SWA-10`'s storage trade-off has no requirement behind it |

Several already have checks that nobody can see, because the link did not exist
until recently: `SWA-01` and `SWA-14` are the `checks` CI job, `SWA-20` is the
`tidy` jobs, `SWA-09` and `SWA-17` are covered by `test_persistence` and
`test_current`. Connecting those to the decisions they verify is tracked work,
not new work.

Three decisions hold today **by discipline alone** and are cheap to make
structural, which is the most valuable unclaimed work at this level:

- `SWA-18`, that the log record is 20 bytes, has no `static_assert` anywhere.
- `SWA-03`, no globals in the core, is true (zero mutable file-scope objects in
  `kiln_core`) and unenforced, because
  `cppcoreguidelines-avoid-non-const-global-variables` is switched off.
- `SWA-02`, time is injected, is true (zero direct clock reads in the core) and
  unenforced. It is a grep.

## 7. Traceability

`SWR-TST-22` requires every requirement to trace to a verification artefact and
`SWR-TST-26` requires test names to carry the requirement identifiers. The
convention exists and has decayed: **28 of 268 requirements** appear in a test
function name, and **147 appear nowhere in any test file at all**. The tool
that was to enforce it, `tools/trace`, was never built.

The recommendation is to stop building it. StrictDoc, which now owns the
requirements, has source traceability: an annotation of the form

```
/* @relation(SWR-SAF-25, scope=function) */
```

ties a test to a requirement, and the existing `requirements` CI job can
publish the coverage matrix as an artefact. That retires a tracked item instead
of adding one, and the gate becomes "no `T` requirement without a claiming
test", ratcheted rather than demanded all at once.

**The honest target is not one test per requirement.** Of 268 requirements,
192 are verifiable by test; the other 76 are inspection (42), demonstration
(21) or analysis (13). Chasing a test for "licences audited" produces either a
fake test or a reclassified requirement, and both are worse than an explicit
split. For those 76, the evidence belongs in the requirements document as a
child node citing the artefact or the commit, so that "verified by inspection"
stops being an unbacked assertion.

`SWR-TST-23` is stricter and worth keeping: every requirement in section 5, the
safety requirements, needs an **automated** test. Inspection is not sufficient
there.

## 8. Coverage

`SWR-TST-19` wants 90 % line coverage of the control and safety components and 100 %
of safety decision branches. The line floor is enforced in CI and was measured
at 97.5 % on `kiln_core`. Branch coverage is around 83 % and is **not** gated,
which tasklist `C10` records.

Coverage is used here as a floor and not as a goal. A safety rule with 100 %
line coverage and no test for the case where its input is absent is covered and
wrong, which is why section 5 of this document exists.

The supervisor is the exception, and deliberately measured differently:
`SWR-TST-29` holds it to 80 % MC/DC, enforced by `tools/mcdc.sh`, for the reason
given in section 2. Two criteria rather than one because the components differ:
`kiln_core` is large and its risk is breadth, so a line floor across it is the
useful number; the supervisor is small and its risk is a single unevaluated
condition, so condition coverage is the useful number. One number applied to
both would be the wrong number for one of them.

## 9. What is deliberately not tested

- **The external over-temperature cutout** (`SYS-HW-13`). It is outside the product
  and mandatory; the project tests that it is not relied upon, not that it
  works.
- **Mains-voltage behaviour of the installation.** `SYS-ASM-04` assumes competent
  installation.
- **Real firings, as a gate.** A kiln takes a day. Long-duration behaviour is
  verified by accelerated simulation and a soak test (`SWR-TST-21`), not by waiting.
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

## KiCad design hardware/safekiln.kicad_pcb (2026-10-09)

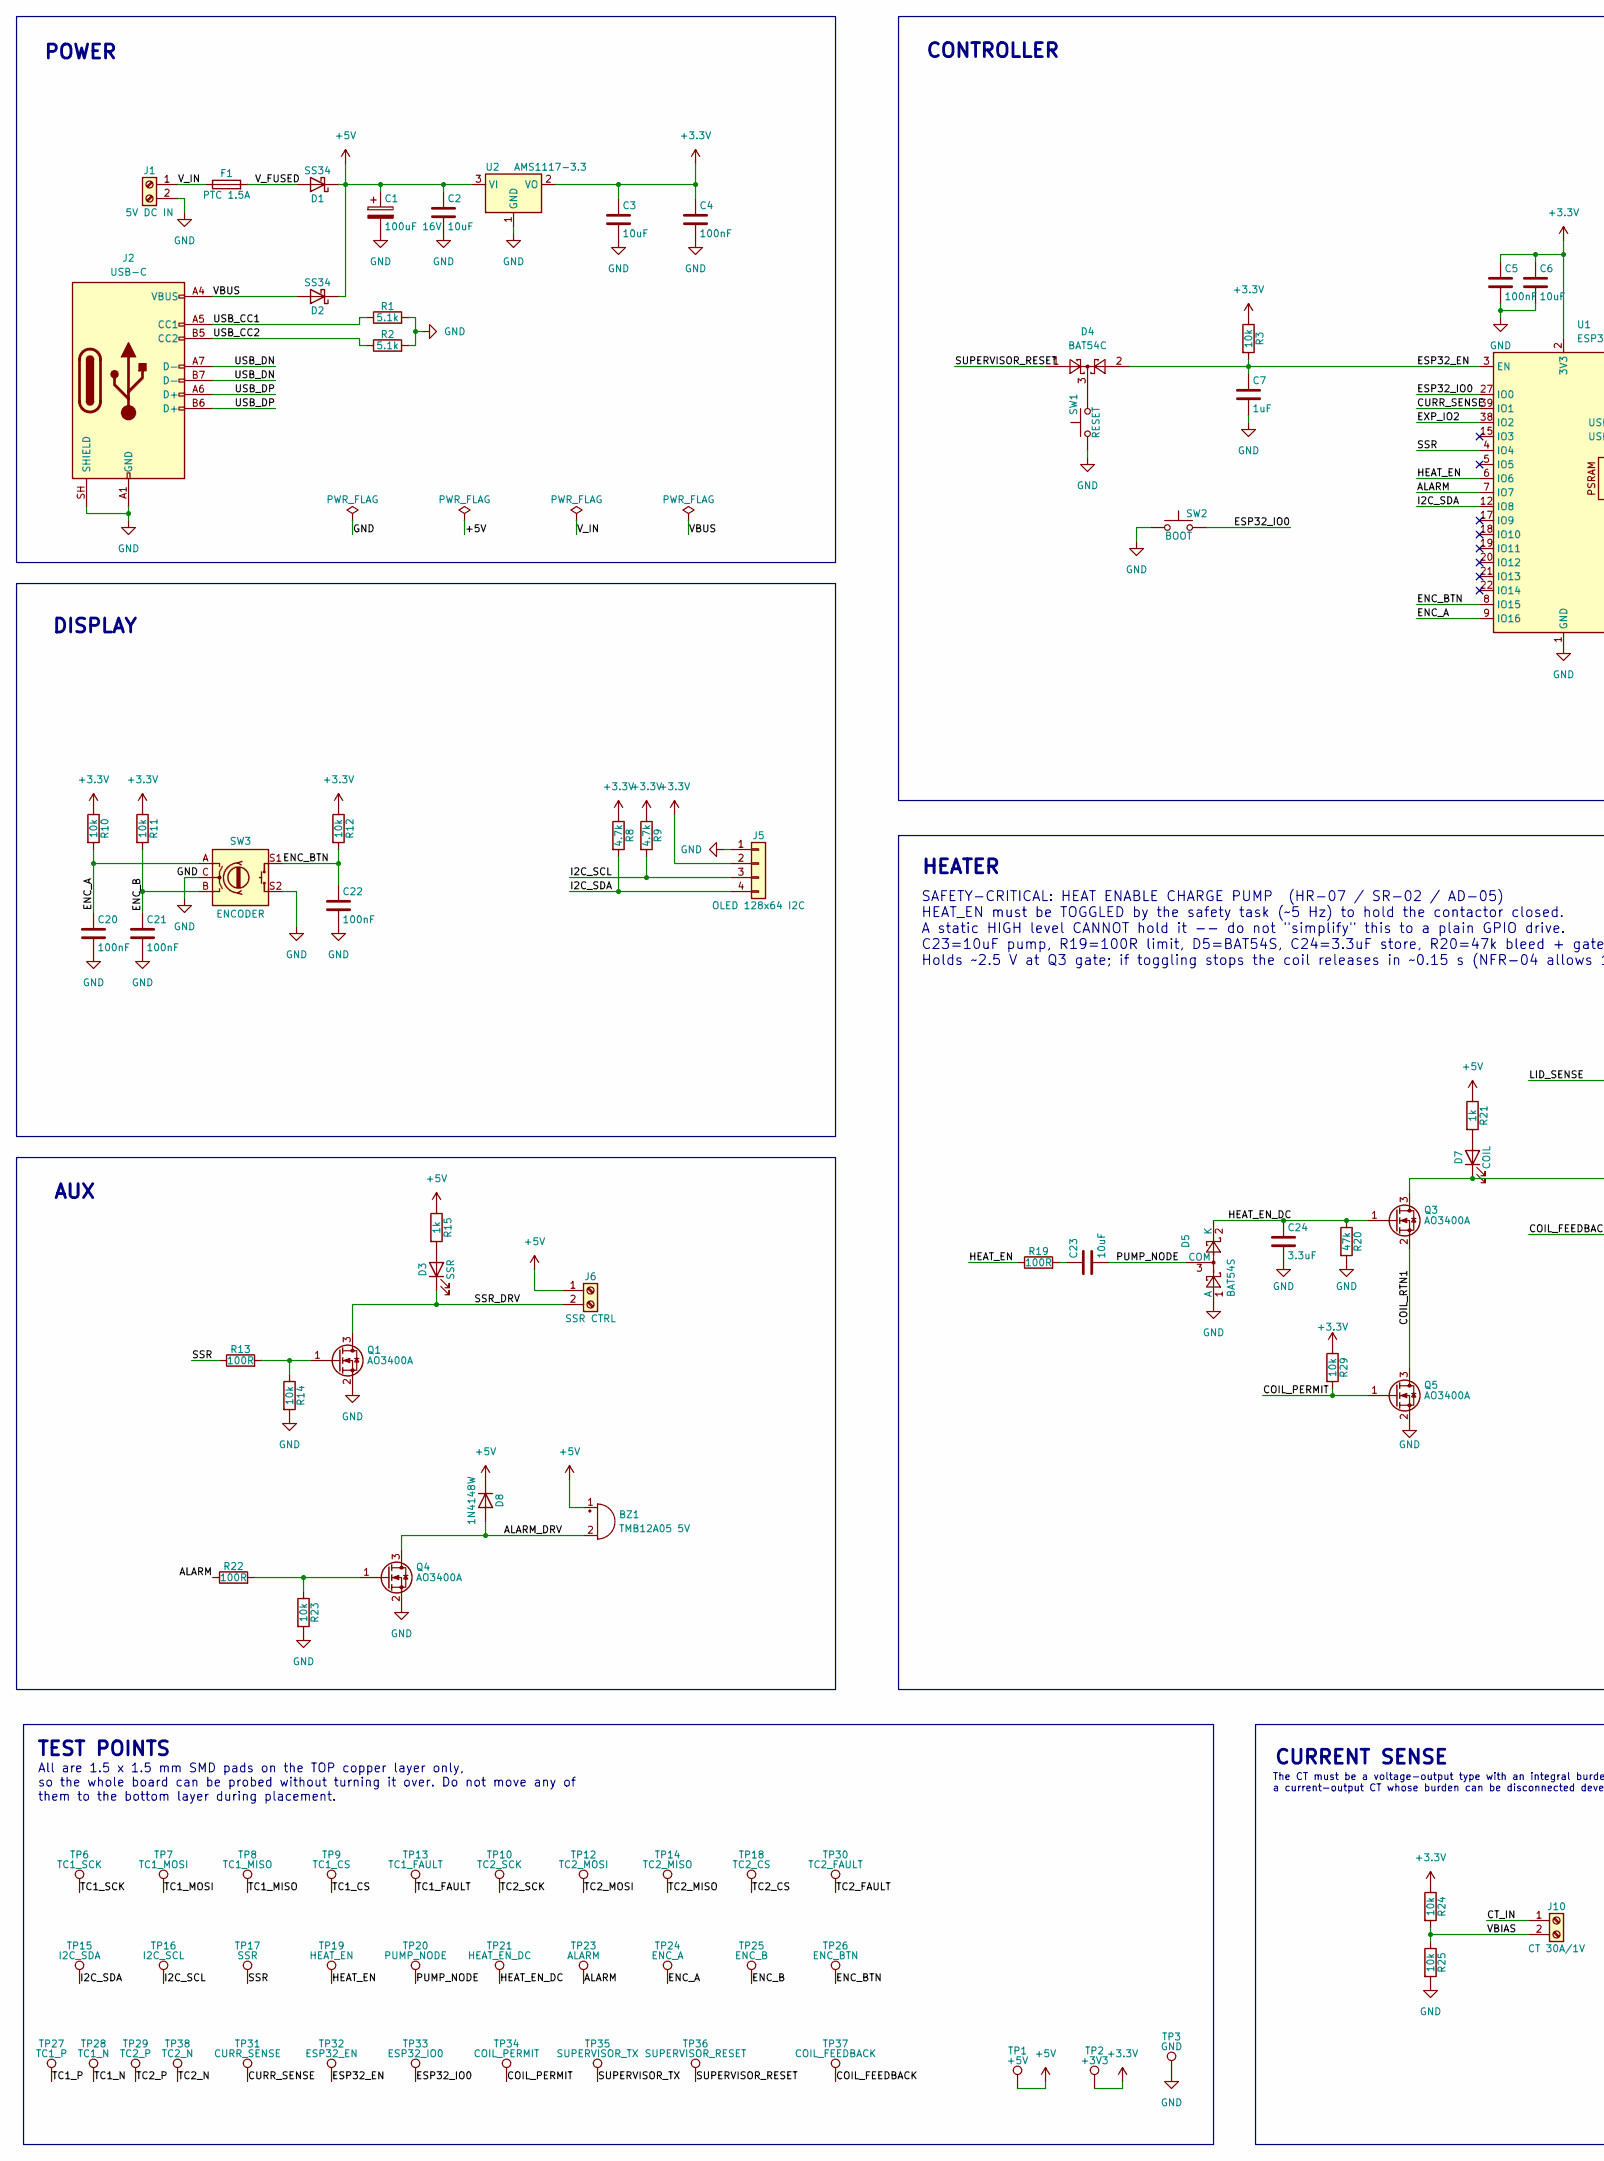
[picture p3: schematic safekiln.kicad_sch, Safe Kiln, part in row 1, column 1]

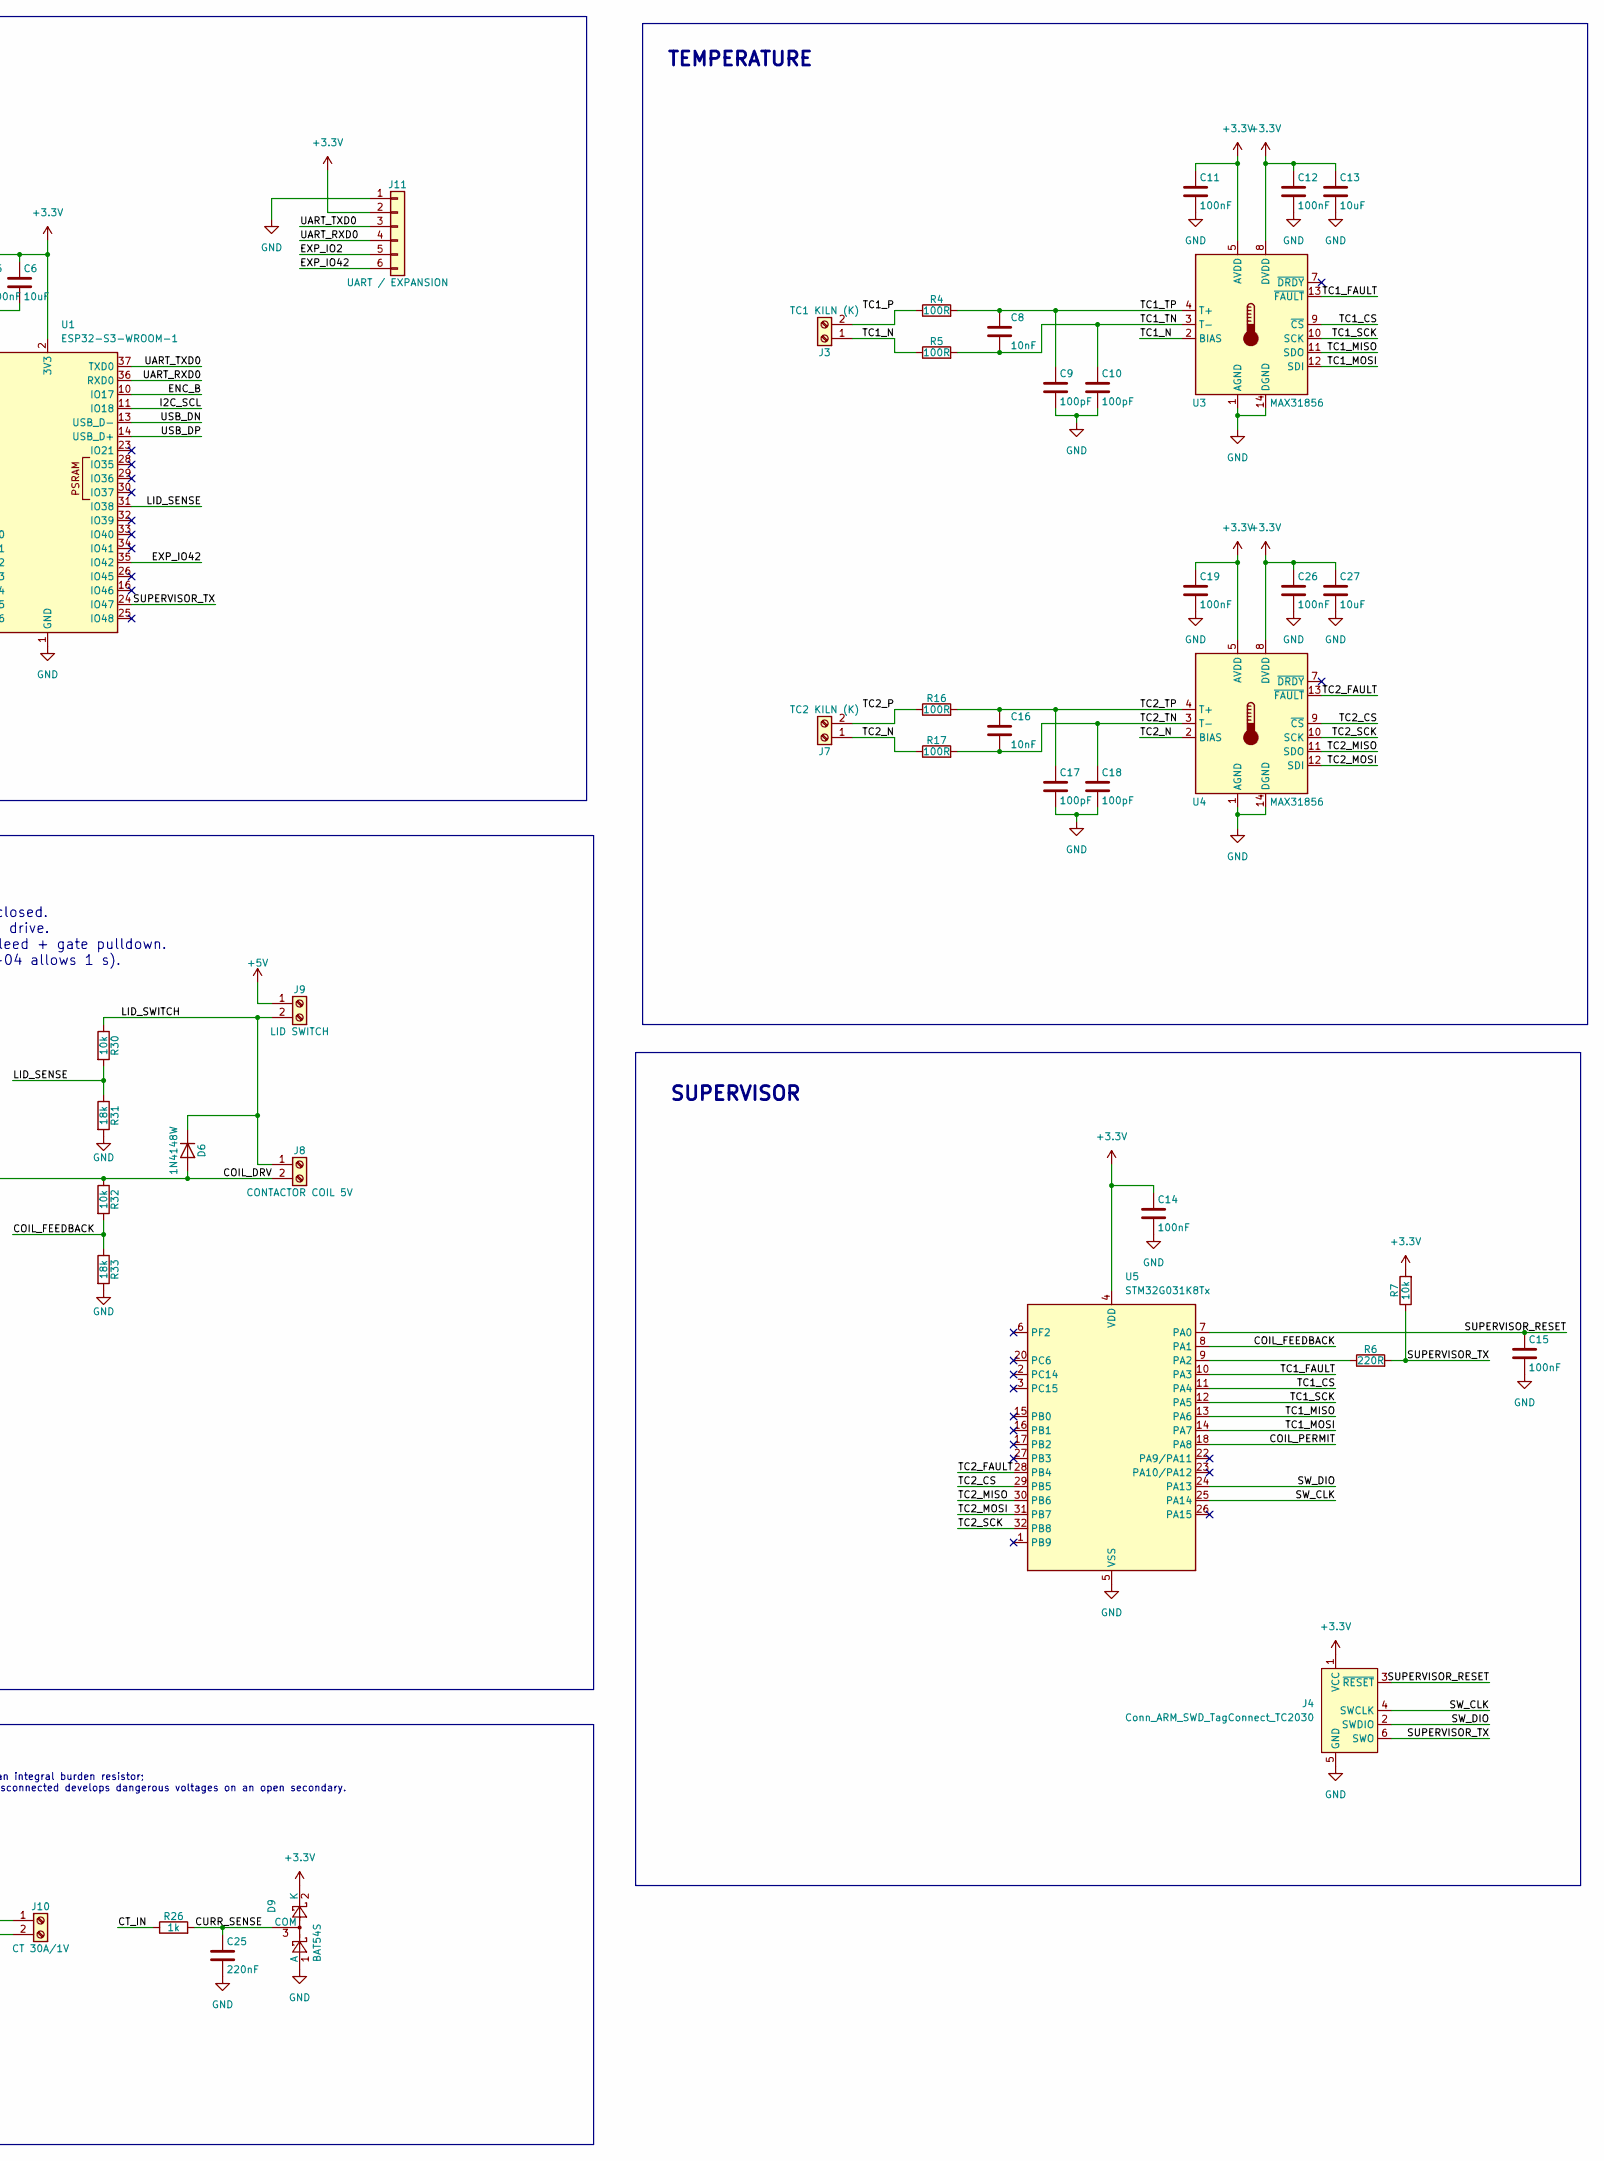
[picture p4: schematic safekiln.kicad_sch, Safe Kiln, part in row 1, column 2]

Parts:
BZ1: TMB12A05 5V; Buzzer_12x9.5RM7.6; LCSC C96093
C1: 100uF 16V; CP_Elec_6.3x7.7; LCSC C231174
C2, C3, C6, C13, C23, C27: 10uF; C_0805_2012Metric; LCSC C15850
C4, C5, C11, C12, C14, C15, C19, C20, C21, C22, C26: 100nF; C_0402_1005Metric; LCSC C1525
C7: 1uF; C_0402_1005Metric; LCSC C52923
C8, C16: 10nF; C_0402_1005Metric; LCSC C15195
C9, C10, C17, C18: 100pF; C_0402_1005Metric; LCSC C26409
C24: 3.3uF; C_0805_2012Metric; LCSC C159781
C25: 220nF; C_0402_1005Metric; LCSC C16772
D1, D2: SS34; D_SMA; LCSC C8678
D3: SSR; LED_0603_1608Metric; LCSC C2286
D4: BAT54C; SOT-23
D5, D9: BAT54S; SOT-23; LCSC C19726
D6, D8: 1N4148W; D_SOD-123; LCSC C2099
D7: COIL; LED_0603_1608Metric; LCSC C2286
F1: PTC 1.5A; Fuse_1206_3216Metric; LCSC C20802
J1: 5V DC IN; TerminalBlock_MaiXu_MX126-5.0-02P_1x02_P5.00mm; LCSC C474881
J2: USB-C; USB_C_Receptacle_HRO_TYPE-C-31-M-12; LCSC C165948
J3: TC1 KILN (K); TerminalBlock_MaiXu_MX126-5.0-02P_1x02_P5.00mm; LCSC C474881
J4: Conn_ARM_SWD_TagConnect_TC2030; Tag-Connect_TC2030-IDC-NL_2x03_P1.27mm_Vertical
J5: OLED 128x64 I2C; PinHeader_1x04_P2.54mm_Vertical; LCSC C2691448
J6: SSR CTRL; TerminalBlock_MaiXu_MX126-5.0-02P_1x02_P5.00mm; LCSC C474881
J7: TC2 KILN (K); TerminalBlock_MaiXu_MX126-5.0-02P_1x02_P5.00mm; LCSC C474881
J8: CONTACTOR COIL 5V; TerminalBlock_MaiXu_MX126-5.0-02P_1x02_P5.00mm; LCSC C474881
J9: LID SWITCH; TerminalBlock_MaiXu_MX126-5.0-02P_1x02_P5.00mm; LCSC C474881
J10: CT 30A/1V; TerminalBlock_MaiXu_MX126-5.0-02P_1x02_P5.00mm; LCSC C474881
J11: UART / EXPANSION; PinHeader_1x06_P2.54mm_Vertical; LCSC C492405
Q1, Q3, Q4: AO3400A; SOT-23; LCSC C20917
Q5: AO3400A; SOT-23
R1, R2: 5.1k; R_0402_1005Metric; LCSC C25905
R3, R10, R11, R12, R14, R23, R24, R25: 10k; R_0402_1005Metric; LCSC C25744
R4, R5, R13, R16, R17, R19, R22: 100R; R_0402_1005Metric; LCSC C25076
R6: 220R; R_0402_1005Metric; LCSC C25076
R7: 10k; R_0402_1005Metric; LCSC C25076
R8, R9: 4.7k; R_0402_1005Metric; LCSC C25900
R15, R21, R26: 1k; R_0402_1005Metric; LCSC C11702
R20: 47k; R_0402_1005Metric; LCSC C25792
R29, R30, R32: 10k; R_0402_1005Metric
R31, R33: 18k; R_0402_1005Metric
SW1: RESET; SW_PUSH_6mm_H5mm; LCSC C111609
SW2: BOOT; SW_PUSH_6mm_H5mm; LCSC C111609
SW3: ENCODER; RotaryEncoder_Alps_EC11E-Switch_Vertical_H20mm; LCSC C7275025
TP1: +5V; TestPoint_Pad_1.5x1.5mm
TP2: +3V3; TestPoint_Pad_1.5x1.5mm
TP3: GND; TestPoint_Pad_1.5x1.5mm
TP6: TC1_SCK; TestPoint_Pad_1.5x1.5mm
TP7: TC1_MOSI; TestPoint_Pad_1.5x1.5mm
TP8: TC1_MISO; TestPoint_Pad_1.5x1.5mm
TP9: TC1_CS; TestPoint_Pad_1.5x1.5mm
TP10: TC2_SCK; TestPoint_Pad_1.5x1.5mm
TP12: TC2_MOSI; TestPoint_Pad_1.5x1.5mm
TP13: TC1_FAULT; TestPoint_Pad_1.5x1.5mm
TP14: TC2_MISO; TestPoint_Pad_1.5x1.5mm
TP15: I2C_SDA; TestPoint_Pad_1.5x1.5mm
TP16: I2C_SCL; TestPoint_Pad_1.5x1.5mm
TP17: SSR; TestPoint_Pad_1.5x1.5mm
TP18: TC2_CS; TestPoint_Pad_1.5x1.5mm
TP19: HEAT_EN; TestPoint_Pad_1.5x1.5mm
TP20: PUMP_NODE; TestPoint_Pad_1.5x1.5mm
TP21: HEAT_EN_DC; TestPoint_Pad_1.5x1.5mm
TP23: ALARM; TestPoint_Pad_1.5x1.5mm
TP24: ENC_A; TestPoint_Pad_1.5x1.5mm
TP25: ENC_B; TestPoint_Pad_1.5x1.5mm
TP26: ENC_BTN; TestPoint_Pad_1.5x1.5mm
TP27: TC1_P; TestPoint_Pad_1.5x1.5mm
TP28: TC1_N; TestPoint_Pad_1.5x1.5mm
TP29: TC2_P; TestPoint_Pad_1.5x1.5mm
TP30: TC2_FAULT; TestPoint_Pad_1.5x1.5mm
TP31: CURR_SENSE; TestPoint_Pad_1.5x1.5mm
TP32: ESP32_EN; TestPoint_Pad_1.5x1.5mm
TP33: ESP32_IO0; TestPoint_Pad_1.5x1.5mm
TP34: COIL_PERMIT; TestPoint_Pad_1.5x1.5mm
TP35: SUPERVISOR_TX; TestPoint_Pad_1.5x1.5mm
TP36: SUPERVISOR_RESET; TestPoint_Pad_1.5x1.5mm
TP37: COIL_FEEDBACK; TestPoint_Pad_1.5x1.5mm
TP38: TC2_N; TestPoint_Pad_1.5x1.5mm
U1: ESP32-S3-WROOM-1; LCSC C2913198
U2: AMS1117-3.3; SOT-223-3_TabPin2; LCSC C6186
U3, U4: MAX31856; TSSOP-14_4.4x5mm_P0.65mm; LCSC C2653162
U5: STM32G031K8Tx; LQFP-32_7x7mm_P0.8mm

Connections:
+3.3V: C3.1, C4.1, C5.1, C6.1, C11.1, C12.1, C13.1, C14.1, C19.1, C26.1, C27.1, D9.2 (K), J4.1 (VCC), J5.2, J11.2, R3.1, R7.2, R8.1, R9.1, R10.1, R11.1, R12.1, R24.1, R29.1, TP2.1 (1_1), U1.2 (3V3), U2.2 (VO), U3.5 (AVDD), U3.8 (DVDD), U4.5 (AVDD), U4.8 (DVDD), U5.4 (VDD)
+5V: BZ1.1 (+), C1.1, C2.1, D1.1 (K), D2.1 (K), D8.1 (K), J6.1, J9.1, R15.1, R21.1, TP1.1 (1_1), U2.3 (VI)
/ALARM: R22.1, TP23.1 (1_1), U1.7 (IO7)
/ALARM_DRV: BZ1.2 (-), D8.2 (A), Q4.3 (D)
/COIL_DRV: D6.2 (A), D7.1 (K), J8.2, Q3.3 (D), R32.1
/COIL_FEEDBACK: R32.2, R33.1, TP37.1 (1_1), U5.8 (PA1)
/COIL_PERMIT: Q5.1 (G), R29.2, TP34.1 (1_1), U5.18 (PA8)
/COIL_RTN1: Q3.2 (S), Q5.3 (D)
/CT_IN: J10.1, R26.1
/CURR_SENSE: C25.1, D9.3 (COM), R26.2, TP31.1 (1_1), U1.39 (IO1)
/ENC_A: C20.1, R10.2, SW3.A, TP24.1 (1_1), U1.9 (IO16)
/ENC_B: C21.1, R11.2, SW3.B, TP25.1 (1_1), U1.10 (IO17)
/ENC_BTN: C22.1, R12.2, SW3.S1, TP26.1 (1_1), U1.8 (IO15)
/ESP32_EN: C7.1, D4.2, R3.2, TP32.1 (1_1), U1.3 (EN)
/ESP32_IO0: SW2.2, TP33.1 (1_1), U1.27 (IO0)
/EXP_IO2: J11.5, U1.38 (IO2)
/EXP_IO42: J11.6, U1.35 (IO42)
/HEAT_EN: R19.1, TP19.1 (1_1), U1.6 (IO6)
/HEAT_EN_DC: C24.1, D5.2 (K), Q3.1 (G), R20.1, TP21.1 (1_1)
/I2C_SCL: J5.3, R9.2, TP16.1 (1_1), U1.11 (IO18)
/I2C_SDA: J5.4, R8.2, TP15.1 (1_1), U1.12 (IO8)
/LID_SENSE: R30.2, R31.1, U1.31 (IO38)
/LID_SWITCH: D6.1 (K), J8.1, J9.2, R30.1
/PUMP_NODE: C23.2, D5.3 (COM), TP20.1 (1_1)
/SSR: R13.1, TP17.1 (1_1), U1.4 (IO4)
/SSR_DRV: D3.1 (K), J6.2, Q1.3 (D)
/SUPERVISOR_RESET: C15.1, D4.1, J4.3 (~RESET), TP36.1 (1_1), U5.7 (PA0)
/SUPERVISOR_TX: J4.6 (SWO), R6.2, R7.1, TP35.1 (1_1), U1.24 (IO47)
/SW_CLK: J4.4 (SWCLK), U5.25 (PA14)
/SW_DIO: J4.2 (SWDIO), U5.24 (PA13)
/TC1_CS: TP9.1 (1_1), U3.9 (~CS), U5.11 (PA4)
/TC1_FAULT: TP13.1 (1_1), U3.13 (~FAULT), U5.10 (PA3)
/TC1_MISO: TP8.1 (1_1), U3.11 (SDO), U5.13 (PA6)
/TC1_MOSI: TP7.1 (1_1), U3.12 (SDI), U5.14 (PA7)
/TC1_N: J3.1, R5.1, TP28.1 (1_1), U3.2 (BIAS)
/TC1_P: J3.2, R4.1, TP27.1 (1_1)
/TC1_SCK: TP6.1 (1_1), U3.10 (SCK), U5.12 (PA5)
/TC1_TN: C8.2, C10.1, R5.2, U3.3 (T-)
/TC1_TP: C8.1, C9.1, R4.2, U3.4 (T+)
/TC2_CS: TP18.1 (1_1), U4.9 (~CS), U5.29 (PB5)
/TC2_FAULT: TP30.1 (1_1), U4.13 (~FAULT), U5.28 (PB4)
/TC2_MISO: TP14.1 (1_1), U4.11 (SDO), U5.30 (PB6)
/TC2_MOSI: TP12.1 (1_1), U4.12 (SDI), U5.31 (PB7)
/TC2_N: J7.1, R17.1, TP38.1 (1_1), U4.2 (BIAS)
/TC2_P: J7.2, R16.1, TP29.1 (1_1)
/TC2_SCK: TP10.1 (1_1), U4.10 (SCK), U5.32 (PB8)
/TC2_TN: C16.2, C18.1, R17.2, U4.3 (T-)
/TC2_TP: C16.1, C17.1, R16.2, U4.4 (T+)
/UART_RXD0: J11.4, U1.36 (RXD0)
/UART_TXD0: J11.3, U1.37 (TXD0)
/USB_CC1: J2.A5 (CC1), R1.1
/USB_CC2: J2.B5 (CC2), R2.1
/USB_DN: J2.A7 (D-), J2.B7 (D-), U1.13 (USB_D-)
/USB_DP: J2.A6 (D+), J2.B6 (D+), U1.14 (USB_D+)
/VBIAS: J10.2, R24.2, R25.1
/VBUS: D2.2 (A), J2.A4 (VBUS), J2.A9 (VBUS), J2.B4 (VBUS), J2.B9 (VBUS)
/V_FUSED: D1.2 (A), F1.2
/V_IN: F1.1, J1.1
GND: C1.2, C2.2, C3.2, C4.2, C5.2, C6.2, C7.2, C9.2, C10.2, C11.2, C12.2, C13.2, C14.2, C15.2, C17.2, C18.2, C19.2, C20.2, C21.2, C22.2, C24.2, C25.2, C26.2, C27.2, D5.1 (A), D9.1 (A), J1.2, J2.A1 (GND), J2.A12 (GND), J2.B1 (GND), J2.B12 (GND), J2.SH (SHIELD), J4.5 (GND), J5.1, J11.1, Q1.2 (S), Q4.2 (S), Q5.2 (S), R1.2, R2.2, R14.2, R20.2, R23.2, R25.2, R31.2, R33.2, SW1.1, SW2.1, SW3.C, SW3.S2, TP3.1 (1_1), U1.1 (GND), U1.40 (GND), U1.41 (GND), U2.1 (GND), U3.1 (AGND), U3.14 (DGND), U4.1 (AGND), U4.14 (DGND), U5.5 (VSS)
unnamed: C23.1, R19.2
unnamed: D3.2 (A), R15.2
unnamed: D4.3, SW1.2
unnamed: D7.2 (A), R21.2
unnamed: Q1.1 (G), R13.2, R14.1
unnamed: Q4.1 (G), R22.2, R23.1
unnamed: R6.1, U5.9 (PA2)

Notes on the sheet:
The CT must be a voltage-output type with an integral burden resistor; a current-output CT whose burden can be disconnected develops dangerous voltages on an open secondary.
TEMPERATURE
DISPLAY
TEST POINTS
SAFETY-CRITICAL: HEAT ENABLE CHARGE PUMP (HR-07 / SR-02 / AD-05) HEAT_EN must be TOGGLED by the safety task (~5 Hz) to hold the contactor closed. A static HIGH level CANNOT hold it -- do not "simplify" this to a plain GPIO drive. C23=10uF pump, R19=100R limit, D5=BAT54S, C24=3.3uF store, R20=47k bl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
CURRENT SENSE
POWER
AUX
HEATER
CONTROLLER
SUPERVISOR
All are 1.5 x 1.5 mm SMD pads on the TOP copper layer only, so the whole board can be probed without turning it over. Do not move any of them to the bottom layer during placement.

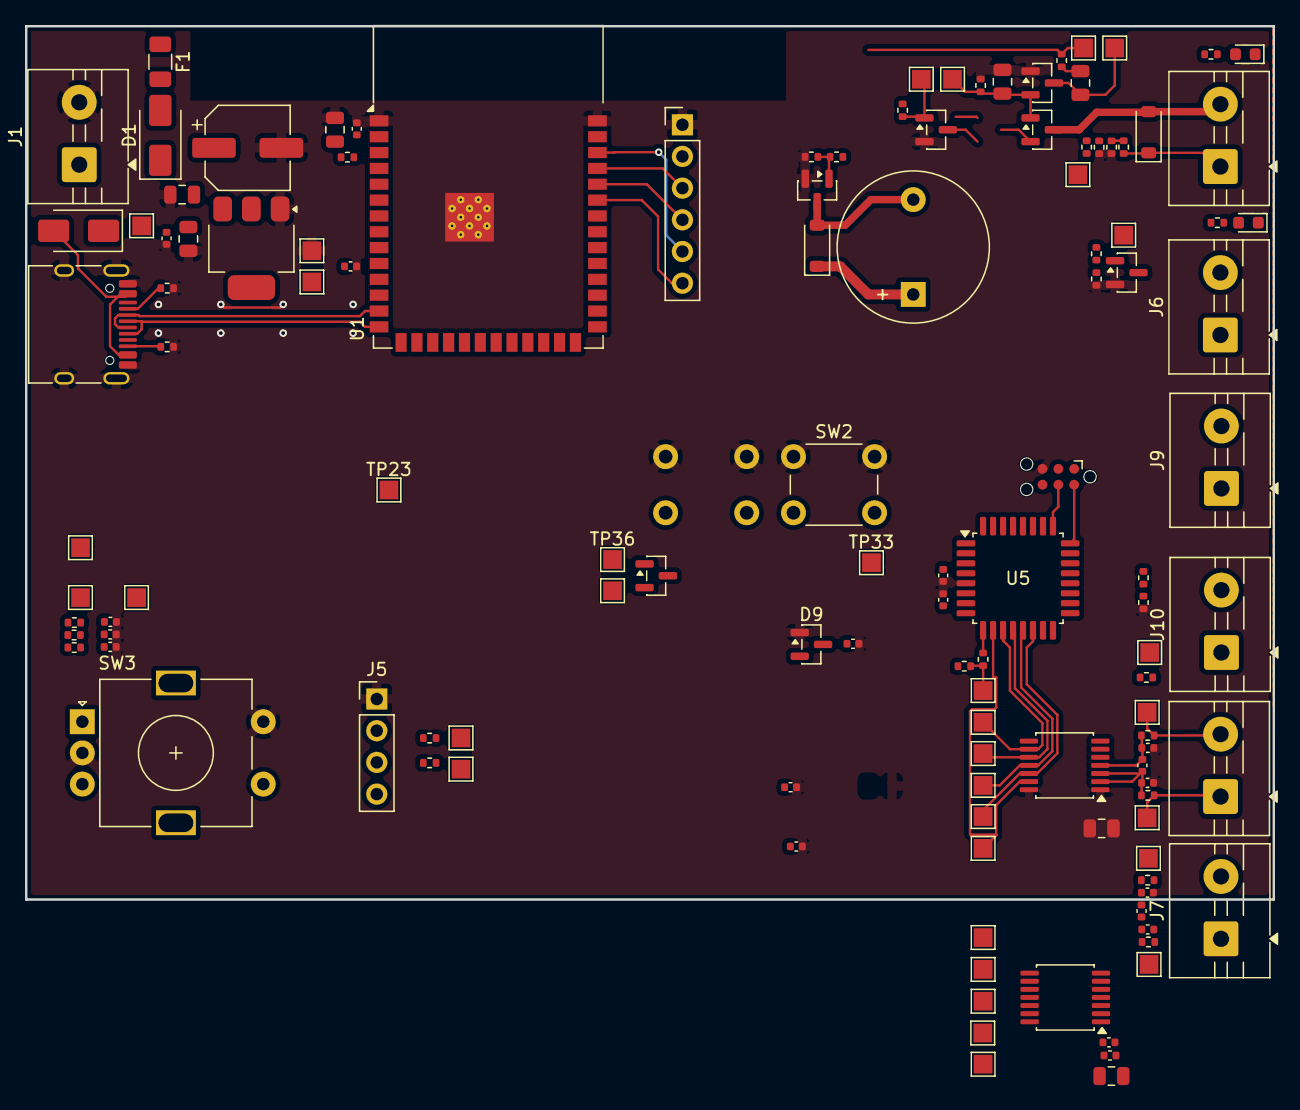
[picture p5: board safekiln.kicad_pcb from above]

Board: 2 copper layers, 100.0 x 70.0 mm, 125 parts (1 on the bottom side), 66 nets.

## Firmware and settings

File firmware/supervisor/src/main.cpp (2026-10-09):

/* SPDX-FileCopyrightText: 2026 Bitcrush Testing
 * SPDX-License-Identifier: GPL-3.0-or-later
 *
 * The supervisor's composition root: bring up the peripherals, then run one
 * loop at 10 Hz that reads, decides and reports.
 *
 * Everything that *decides* is in sup_core and is tested on the host.  What is
 * here is the part that needs the silicon, which is the same split SWA-01 makes
 * on the other side of the link and for the same reason.
 *
 * ---------------------------------------------------------------------------
 * STATE: the peripheral bring-up below is NOT yet verified
 * ---------------------------------------------------------------------------
 * The trip logic, the wire format and the MAX31856 register decode are complete
 * and tested on the host; the decode lives in sup_core for that reason, and this
 * file holds only the transaction that feeds it.
 *
 * What remains unverified is the transport: the register sequences here are
 * written against ST's RM0444 and the MAX31856 datasheet but have never run on
 * silicon, and the alternate-function numbers in pins.h are unconfirmed (see the
 * note there).  They are deliberately kept as small, separate functions so each
 * can be brought up and checked one at a time.  Tasklist R6 and R8 cover that
 * work.
 *
 * Every spin in this file is bounded.  A supervisor that can be stalled by a
 * wedged peripheral has put its peripherals ahead of its job, and the two that
 * could stall it are the SPI exchange on the path that decides whether heat is
 * permitted, and the UART on the path that only reports.  Both give up rather
 * than wait; the SPI timeout yields a burst of zeros, which the decode already
 * reports as a comms fault, and an abandoned frame reads to the ESP32 as
 * silence, which it already withholds heat on.
 */
#include <stdint.h>

#include "cortex_m0plus.h"
#include "pins.h"
#include "stm32g031.h"
#include "sup/max31856.h"
#include "sup/selfcheck.h"
#include "sup/trip.h"
#include "sup_proto.h"

/* The expected CRC of the program image, stamped into .sup_crc after linking by
 * tools/sup-crc.py.
 *
 * `const` and NOT `volatile const`, which is the opposite of the obvious
 * choice and matters: a volatile object is emitted into a WRITABLE section, and
 * a writable section in the flash region gives the output an RWX LOAD segment
 * that the linker warns about. It is read through a volatile pointer at the use
 * site instead, which stops the compiler folding the placeholder into the
 * comparison and optimising the whole check away while keeping the datum in
 * read-only memory where it belongs. */
extern "C" {
/* `extern` on the definition is load-bearing too: a `const` at namespace scope
 * has INTERNAL linkage in C++, which would leave the stamping tool hunting a
 * mangled local symbol instead of a plain name. */
extern const uint32_t sup_expected_crc;
__attribute__((section(".sup_crc"), used))
const uint32_t sup_expected_crc = SUP_CRC_UNPROGRAMMED;
extern const uint8_t _sup_crc_region_start[];
extern const uint8_t _sup_crc_region_end[];
extern uint32_t _sup_stack_guard_start[];
extern uint32_t _sup_stack_guard_end[];
}

namespace {

/* HSI16 is the reset default: 16 MHz, no PLL, no external crystal, and ample
 * for a 10 Hz loop.  Running from the internal oscillator is also one less
 * component whose failure the supervisor would have to survive, and the IWDG
 * has its own oscillator regardless (see board_watchdog_init). */
constexpr uint32_t SUP_SYSCLK_HZ = 16000000u;
constexpr uint32_t SUP_UART_BAUD = 115200u;

/* 10 Hz, matching the report rate the link is specified at and the cycle the
 * ESP32's own supervisor task runs.
 *
 * The period is handed to sup_step in milliseconds rather than seconds in a
 * float, so the two constants below are the same number twice and a
 * static_assert says so: a cycle whose timing and whose reported interval
 * disagreed would make every latch timer wrong by that ratio, silently. */
constexpr uint32_t CYCLE_HZ    = 10u;
constexpr uint32_t CYCLE_MS    = 100u;
static_assert(CYCLE_MS * CYCLE_HZ == 1000u, "CYCLE_MS must be the period of CYCLE_HZ");

/* SysTick reload for one cycle.  The counter is a down-counter that reloads on
 * reaching zero, so the period is RVR + 1 ticks: the reload holds one less than
 * the count.
 *
 * This is the whole of what used to be a calibrated nop loop.  SWR-ACQ-03 gives
 * the cycle period a +/-10 % tolerance, and a spin loop cannot hold one: it
 * drifts with the compiler, the optimisation level and anything added to the
 * loop body, and it is wrong by construction the moment the body does more work
 * on one pass than another.  SysTick is derived from the same clock the
 * tolerance is specified against. */
constexpr uint32_t CYCLE_RELOAD = (SUP_SYSCLK_HZ / CYCLE_HZ) - 1u;
static_assert(CYCLE_RELOAD <= SYST_RVR_MAX,
              "one cycle does not fit in SysTick's 24 bits; a reload that is "
              "truncated is a silently faster cycle, not a slower one");

/* How long tc_init waits for the front end's first conversion.
 *
 * The MAX31856 needs a few hundred milliseconds to produce its first reading
 * with 4-sample averaging and 50 Hz rejection, and until it does the
 * temperature registers read zero.  Zero is in range and carries no fault bit,
 * so it would decode as a perfectly plausible 0 degC and permit heat.  Waiting
 * for a real conversion before sup_init is what stops a boot-time reading of
 * "cold" on a kiln that is not.
 *
 * Generous on purpose: a failed self-test latches SUP_TRIP_SELF_TEST, which
 * sup_clear deliberately refuses to clear, so this must not be a race that a
 * slow part can lose.  20 cycles is 2 s against an expected 0.3 s. */
constexpr uint32_t TC_FIRST_CONVERSION_CYCLES = 20u;

/* IWDG, in LSI ticks of nominally 2 ms (see board_watchdog_init).
 *
 *   reload 175  ->  352 ms timeout, which is comfortably longer than one cycle
 *                   and comfortably shorter than NFR-04's 500 ms budget.
 *   window 140  ->  a feed is refused until 35 ticks have elapsed, so a cycle
 *                   much shorter than 70 ms resets.
 *
 * The window must stay ABOVE the worst-case counter value at feed time, which
 * with a +/-10 % LSI is 130, or a healthy board resets itself. 140 is that plus
 * 10 ticks of margin. */
constexpr uint32_t IWDG_RELOAD = 175u;
constexpr uint32_t IWDG_WINDOW = 140u;
static_assert(IWDG_WINDOW < IWDG_RELOAD,
              "a window at or above the reload refuses every feed");
static_assert(IWDG_RELOAD - IWDG_WINDOW >= 20u,
              "too little of the period is inside the window: a healthy cycle "
              "would be rejected as early");
static_assert(IWDG_WINDOW >= 135u,
              "the window has to clear the worst-case counter at feed time, "
              "which a 10 % fast LSI puts at 130");

/* --- board, unverified -------------------------------------------------- */

void board_clocks_init()
{
    /* Reset defaults are kept: HSI16, flash latency 0, which is valid at
     * 16 MHz.  Stated rather than written, so a later change to the clock has
     * to come back here and reconsider the latency. */
    RCC_IOPENR  |= SUP_RCC_IOPENR_PORTA | SUP_RCC_IOPENR_PORTB;
    RCC_APBENR2 |= SUP_RCC_APBENR2_SPI1;
    RCC_APBENR1 |= SUP_RCC_APBENR1_USART2 | SUP_RCC_APBENR1_SPI2;
}

/* A port, as the four registers the bring-up touches.
 *
 * Introduced because the second thermocouple's bus is on port B: the helpers
 * were GPIOA-only, and a second copy of each differing in one identifier is how
 * the two drift apart. The register macros expand to dereferences, so taking
 * their address gives back the constant pointer. */
struct gpio_port {
    volatile uint32_t *moder;
    volatile uint32_t *pupdr;
    volatile uint32_t *afrl;
    volatile uint32_t *afrh;
    volatile uint32_t *bsrr;
    volatile uint32_t *idr;
};

const gpio_port PORT_A = { &GPIOA_MODER, &GPIOA_PUPDR, &GPIOA_AFRL,
                           &GPIOA_AFRH, &GPIOA_BSRR, &GPIOA_IDR };
const gpio_port PORT_B = { &GPIOB_MODER, &GPIOB_PUPDR, &GPIOB_AFRL,
                           &GPIOB_AFRH, &GPIOB_BSRR, &GPIOB_IDR };

void pin_mode(const gpio_port &g, unsigned pin, unsigned mode, unsigned pull)
{
    *g.moder = (*g.moder & ~(3u << (pin * 2u))) | (mode << (pin * 2u));
    *g.pupdr = (*g.pupdr & ~(3u << (pin * 2u))) | (pull << (pin * 2u));
}

void pin_af(const gpio_port &g, unsigned pin, unsigned af)
{
    if (pin < 8u) {
        *g.afrl = (*g.afrl & ~(0xFu << (pin * 4u))) | (af << (pin * 4u));
    } else {
        const unsigned p = pin - 8u;
        *g.afrh = (*g.afrh & ~(0xFu << (p * 4u))) | (af << (p * 4u));
    }
}

void pin_set(const gpio_port &g, unsigned pin, bool high)
{
    *g.bsrr = high ? (1u << pin) : (1u << (pin + 16u));
}

bool pin_is_high(const gpio_port &g, unsigned pin)
{
    return (*g.idr & (1u << pin)) != 0u;
}

void board_gpio_init()
{
    /* The permit line was already driven low in reset_handler, before .data
     * was copied.  Re-stating the mode here is harmless and keeps this
     * function a complete description of the pin states. */
    pin_mode(PORT_A, SUP_PIN_PERMIT, 1u, 0u);           /* output, no pull */
    pin_mode(PORT_A, SUP_PIN_TC_CS,  1u, 0u);
    pin_set(PORT_A, SUP_PIN_TC_CS, true);               /* ~CS idle high */

    pin_mode(PORT_A, SUP_PIN_TC_FAULT, 0u, 1u);         /* input, pull-up */
    pin_mode(PORT_A, SUP_PIN_CLEAR,    0u, 1u);

    /* SWR-SAF-38: the permit readback. No pull, because the board's divider
     * defines the level and a pull would fight it. */
    pin_mode(PORT_A, SUP_PIN_PERMIT_SENSE, 0u, 0u);

    pin_af(PORT_A, SUP_PIN_SPI_SCK,  SUP_AF_SPI1);
    pin_af(PORT_A, SUP_PIN_SPI_MISO, SUP_AF_SPI1);
    pin_af(PORT_A, SUP_PIN_SPI_MOSI, SUP_AF_SPI1);
    pin_mode(PORT_A, SUP_PIN_SPI_SCK,  2u, 0u);         /* alternate function */
    pin_mode(PORT_A, SUP_PIN_SPI_MISO, 2u, 0u);
    pin_mode(PORT_A, SUP_PIN_SPI_MOSI, 2u, 0u);

    pin_af(PORT_A, SUP_PIN_UART_TX, SUP_AF_USART2);
    pin_mode(PORT_A, SUP_PIN_UART_TX, 2u, 0u);

    /* --- port B: the second couple's bus (SWR-SAF-37) -------------------
     *
     * Three DIFFERENT alternate function numbers, which is the trap here and the
     * reason pins.h shouts about it: MISO is AF4 while SCK and MOSI are AF1.
     * One shared constant would configure MISO as something else entirely and
     * the bus would read nothing, with no error reported anywhere. */
    pin_mode(PORT_B, SUP_PIN_TC2_CS, 1u, 0u);
    pin_set(PORT_B, SUP_PIN_TC2_CS, true);              /* ~CS idle high */

    pin_mode(PORT_B, SUP_PIN_TC2_FAULT, 0u, 1u);        /* input, pull-up */

    pin_af(PORT_B, SUP_PIN_SPI2_SCK,  SUP_AF_SPI2_SCK);
    pin_af(PORT_B, SUP_PIN_SPI2_MISO, SUP_AF_SPI2_MISO);
    pin_af(PORT_B, SUP_PIN_SPI2_MOSI, SUP_AF_SPI2_MOSI);
    pin_mode(PORT_B, SUP_PIN_SPI2_SCK,  2u, 0u);
    pin_mode(PORT_B, SUP_PIN_SPI2_MISO, 2u, 0u);
    pin_mode(PORT_B, SUP_PIN_SPI2_MOSI, 2u, 0u);

    /* USART2_RX would be PA3, and PA3 is the ~FAULT input instead.  The link
     * is simplex and the receiver is unwired, not merely unused. */
}

void board_uart_init()
{
    /* 8N1, transmit only.  RE is deliberately not set: with no receive pin
     * configured there is nothing to receive, and leaving the receiver off
     * means a noise burst on an adjacent track cannot even fill a register.
     * Oversampling by 16 is the reset default, so BRR is the plain divisor. */
    USART2_CR1 = 0u;                            /* disable while configuring */
    USART2_BRR = SUP_SYSCLK_HZ / SUP_UART_BAUD;
    USART2_CR2 = 0u;
    USART2_CR3 = 0u;
    USART2_CR1 = (1u << 3) | (1u << 0);         /* TE | UE */
}

void spi_configure(volatile uint32_t *cr1, volatile uint32_t *cr2)
{
    /* SPI1 as master, mode 1, 2 MHz, 8-bit, chip select driven by software.
     *
     * Bit positions are from RM0444's SPI chapter; they are written inline with
     * their names the same way USART2's are above, because naming two dozen
     * one-use bits in a header would be a header nobody reads against a part
     * nobody has the reference manual open for.
     *
     * MODE 1 (CPOL 0, CPHA 1) is the MAX31856's, and it is the one setting here
     * that is not a free choice: mode 0 reads plausible rubbish rather than
     * failing, which the ESP32 adapter records having found out the hard way.
     *
     * 2 MHz is PCLK / 8, matching the ESP32 adapter's clock exactly so the two
     * front ends are driven identically. The part allows 5 MHz; there is nothing
     * to spend the margin on at 10 Hz.
     *
     * SSM and SSI are both set. In master mode with software slave management
     * off, a low NSS input raises MODF and silently drops the peripheral out of
     * master mode; ~CS is a plain GPIO here (PA4), so the internal NSS has to be
     * held high instead of left to float. */
    constexpr uint32_t CR1_CPHA = (1u << 0);
    constexpr uint32_t CR1_MSTR = (1u << 2);
    constexpr uint32_t CR1_BR_DIV8 = (2u << 3);      /* 16 MHz / 8 = 2 MHz   */
    constexpr uint32_t CR1_SPE  = (1u << 6);
    constexpr uint32_t CR1_SSI  = (1u << 8);
    constexpr uint32_t CR1_SSM  = (1u << 9);
    /* DS = 0b0111 is 8-bit, and FRXTH must agree with it: left at its 16-bit
     * default, RXNE would only rise after two bytes and every single-byte
     * exchange would hang. The two are one setting written as two bits. */
    constexpr uint32_t CR2_DS_8BIT = (7u << 8);
    constexpr uint32_t CR2_FRXTH   = (1u << 12);

    *cr1 = 0u;                          /* disable while configuring */
    *cr2 = CR2_DS_8BIT | CR2_FRXTH;
    *cr1 = CR1_CPHA | CR1_MSTR | CR1_BR_DIV8 | CR1_SSI | CR1_SSM;
    *cr1 |= CR1_SPE;
}

/* Both buses, identically configured.
 *
 * SPI2 is a separate peripheral on separate pins, which is the point: a shared
 * bus would have made the second couple's reading depend on the same shift
 * register, the same clock divider and the same chip select logic as the first,
 * and a common-cause failure there would take both readings at once. Two buses
 * cost three pins and buy independence of everything between the MCU core and
 * the two front ends. */
void board_spi_init()
{
    spi_configure(&SPI1_CR1, &SPI1_CR2);
    spi_configure(&SPI2_CR1, &SPI2_CR2);
}

void board_systick_init()
{
    /* Free-running, no interrupt: the loop polls COUNTFLAG. An interrupt would
     * need a vector table entry and a handler whose only job is to set a flag
     * this function could read directly, and the supervisor has nothing else to
     * do while it waits.
     *
     * CVR is cleared so the first period is a whole one rather than whatever the
     * counter happened to hold out of reset. */
    SYST_RVR = CYCLE_RELOAD;
    SYST_CVR = 0u;
    SYST_CSR = SYST_CSR_CLKSOURCE | SYST_CSR_ENABLE;
    (void)SYST_CSR;                     /* clear a COUNTFLAG set by the above */
}
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
int main()
{
    board_clocks_init();
    board_gpio_init();
    board_uart_init();
    board_spi_init();
    /* Before tc_init, which waits whole cycles for the front end's first
     * conversion and therefore needs the timer running. */
    board_systick_init();
    board_watchdog_init();

    /* Three self-tests, all of which must pass before heat can be permitted,
     * and all of which are latched as SUP_TRIP_SELF_TEST, which sup_clear
     * deliberately refuses to clear.
     *
     * The order is deliberate: the clock is checked first because every
     * subsequent timing depends on it, the image second because a corrupt image
     * makes the rest of this function meaningless, and the front end last
     * because it is the one that takes two seconds.
     *
     * tc_init can run for TC_FIRST_CONVERSION_CYCLES, which is 2 s against the
     * watchdog's 350 ms, so the watchdog is fed inside its wait loop. */
    sup_stack_guard_fill(_sup_stack_guard_start, stack_guard_words());

    const bool clk = clock_ok();
    const bool img = flash_ok();
    /* The start-up RAM pass covers the free region in one go, which the
     * periodic walk then re-covers a block at a time (SWR-SAF-33). */
    const bool ram = ram_startup_ok();
    /* Both front ends must configure. A board with only one couple fitted will
     * fail here, which is correct: SWR-SAF-37 makes the second couple part of
     * the product, not an option, and a supervisor that silently ran
     * single-channel would be claiming a cross-check it does not have. Losing a
     * couple LATER is degraded operation and allowed; never having one is a
     * build fault. */
    const bool tc1_ok = tc_init(TC1);
    const bool tc2_ok = tc_init(TC2);
    const bool selftest_ok = clk && img && ram && tc1_ok && tc2_ok;

    sup_t sup;
    sup_init(&sup, selftest_ok);

    uint8_t seq = 0;
    /* The previous cycle's sequence verdict. The flow monitor can only report
     * on a cycle once that cycle has finished, so the result necessarily lands
     * in the next one; at 10 Hz that is a 100 ms delay in reporting a sequence
     * fault, against NFR-04's 500 ms budget. */
    bool prev_flow_ok = true;
    sup_flow_t flow;

    for (;;) {
        sup_flow_begin(&flow);

        const tc_reading tc  = tc_read(TC1);
        const tc_reading tc2 = tc_read(TC2);
        sup_flow_mark(&flow, SUP_FLOW_READ);

        sup_input_t in = {};
        in.chamber_q7    = tc.chamber_q7;
        in.chamber_valid = tc.valid && !pin_low(PORT_A, SUP_PIN_TC_FAULT);
        /* The same two terms as the first couple, and for the same reason. The
         * status register would carry these fault bits over SPI anyway, but it
         * arrives over the very bus whose failure the reading needs qualifying
         * against; the pin is an indication that does not share silicon with the
         * data path. See the note in pins.h. */
        in.chamber2_q7    = tc2.chamber_q7;
        in.chamber2_valid = tc2.valid && !pin_low(PORT_B, SUP_PIN_TC2_FAULT);
        /* The union, so a fault on either front end is reported and acted on.
         * The trip logic does not need to know which one; the flags say which
         * couple is usable and that is what the ESP32 shows. */
        in.fault_bits    = static_cast<uint16_t>(tc.fault_bits | tc2.fault_bits);
        in.permit_sense  = permit_sensed();
        /* The button is a level on a pin; whether it *means* anything is
         * sup_step's decision, because it is edge triggered and held and that
         * belongs in the part that has tests. */
        in.clear_pressed = pin_low(PORT_A, SUP_PIN_CLEAR);

        /* SWR-SAF-36: every periodic diagnostic, in one conjunction. A false
         * here revokes the self-test inside sup_step, which withholds heat for
         * good and cannot be cleared by the button. */
        in.diag_ok = stack_ok() && ram_step() && prev_flow_ok;

        sup_step(&sup, &in, CYCLE_MS);
        sup_flow_mark(&flow, SUP_FLOW_STEP);

        /* The output is driven every cycle rather than on change, so a bit
         * corrupted in the GPIO register is corrected within one cycle. */
        permit(sup.permit);
        sup_flow_mark(&flow, SUP_FLOW_PERMIT);

        sup_report_t rep = {};
        rep.version     = SUP_VERSION;
        rep.seq         = seq++;
        /* Scaled to tenths here, at the wire, which is the only place in the
         * firmware where a temperature changes unit. */
        rep.chamber_dc  = sup_q7_to_dc(tc.chamber_q7);
        rep.cj_dc       = sup_q7_to_dc(tc.cj_q7);
        rep.fault_bits  = tc.fault_bits;
        rep.flags       = sup_flags(&sup, &in);
        rep.trip_reason = sup.reason;

        uint8_t frame[SUP_FRAME_BYTES];
        if (sup_encode(&rep, frame, sizeof(frame)) == SUP_FRAME_BYTES) {
            uart_write(frame, SUP_FRAME_BYTES);
        }
        sup_flow_mark(&flow, SUP_FLOW_REPORT);

        /* Judged here, acted on next cycle. A cycle that skipped the permit
         * stage, or that a corrupted branch entered halfway through, finishes
         * on time and so is invisible to the watchdog; this is what sees it. */
        prev_flow_ok = sup_flow_complete(&flow);

        wait_for_cycle_end();
        /* The only feed in the loop, and deliberately the last statement: it
         * is the one place where a full cycle is known to have elapsed, which
         * the watchdog's window now requires. */
        watchdog_feed();
    }
}

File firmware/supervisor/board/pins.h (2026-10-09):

/* SPDX-FileCopyrightText: 2026 Bitcrush Testing
 * SPDX-License-Identifier: GPL-3.0-or-later
 *
 * The supervisor's pin map for the STM32G031K8T6 (LQFP32).
 *
 * Taken from ST's own data, not from recollection: the package pinout and the
 * alternate-function numbers come from STM32CubeMX's MCU database
 * (db/mcu/STM32G031K(4-6-8)Tx.xml and the GPIO modes file for
 * STM32G03x_gpio_v1_0), and the register bit positions in stm32g031.h come
 * from the CMSIS-SVD.  Both ship with ST's tools, so neither is a build-time
 * fetch (UR-CON-04).
 *
 * ---------------------------------------------------------------------------
 * Three properties this assignment holds on purpose
 * ---------------------------------------------------------------------------
 * 1. THE PERMIT LINE IS ON PORT A, AND MUST STAY THERE.  startup.cpp drives it
 *    low before .data is copied, and to do that it enables exactly one GPIO
 *    clock.  A permit pin that moved to port B would silently break that,
 *    because it would be driven before its port had a clock.
 *
 *    Port B is now in use for the second thermocouple's SPI bus, which is
 *    fine: nothing on port B is touched before main() enables IOPBEN.  The
 *    property that matters is specifically about the permit pin, and it is
 *    stated that way now rather than as "everything on port A", which was the
 *    shape of the rule rather than its reason.
 *
 * 2. PA9 TO PA12 ARE AVOIDED ENTIRELY.  On this package PA11/PA12 can be
 *    remapped to behave as PA9/PA10 through SYSCFG_CFGR1, and positions 19 and
 *    21 are listed as NC-or-PA9/PA10 depending on bonding.  A supervisor's pin
 *    map should not depend on a remap bit being right.
 *
 * 3. THE UART's RECEIVE PIN IS NEVER CONFIGURED.  The link is simplex
 *    (SWR-ACQ-02 fixed the thermocouple type, so there is nothing to send the
 *    supervisor).  USART2_RX would be PA3, and PA3 is used as a plain input
 *    instead, so the receiver is not merely unused, it is unwired.
 */
/**
 * @file pins.h
 * @brief The supervisor pin map for the STM32G031K8T6 (LQFP32).
 *
 * @derivedfrom SWA-22. The assignment itself is in
 *              `firmware/supervisor/README.md`, with the three properties of
 *              it that must survive any change: everything on port A, PA9 to
 *              PA12 avoided entirely, and the UART's receive pin never
 *              configured so the link is unwired rather than merely unused.
 *
 * The `static_assert`s below are the unit design of this file: they prove at
 * compile time that no two pins share a bit and that nothing landed on the
 * remappable PA9..PA14 range.
 */

#ifndef SUP_PINS_H
#define SUP_PINS_H

#include "stm32g031.h"
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

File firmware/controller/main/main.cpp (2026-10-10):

/* SPDX-FileCopyrightText: 2026 Bitcrush Testing
 * SPDX-License-Identifier: GPL-3.0-or-later
 *
 * Composition root -- architecture section 5.3.  The only file in the firmware
 * that binds a port to a concrete adapter, and the only one that creates a task.
 *
 * With CONFIG_KILN_PLANT_SIM the plant is kiln_sim and the firmware runs under
 * QEMU: see sdkconfig.qemu for why substituting at the port boundary is the only
 * thing that can work there, and what it does and does not prove.
 */

#include <stdio.h>
#include <string.h>

#include "freertos/FreeRTOS.h"
#include "freertos/task.h"
#include "esp_log.h"
#include "esp_system.h"
#include "esp_timer.h"
#include "esp_task_wdt.h"
#include "sdkconfig.h"

#include "kiln_app/app.h"
#include "kiln_app/run_index.h"
#include "kiln_app/settings.h"
#include "kiln_core/faults.h"
#include "kiln_core/fileslots.h"
#include "kiln_core/suplink.h"
#include "kiln_core/logring.h"
#include "kiln_core/profile.h"
#include "kiln_hal/hal_esp32s3.h"
#include "kiln_hmi/hmi.h"
#ifndef CONFIG_KILN_PLANT_SIM
#include "kiln_web/httpd.h"
#endif
#include "kiln_ports/port_system.h"

#ifdef CONFIG_KILN_PLANT_SIM
#include "kiln_sim/sim.h"
#include "driver/uart.h"
#endif

namespace {

const char *TAG = "kiln";

} // namespace

/* Periods, from the task table of architecture section 6.1. */
#define WINDOW_PERIOD_MS   10
#define SAFETY_PERIOD_MS  100
#define ACQUIRE_PERIOD_MS 250
#define CONTROL_PERIOD_MS 1000

#ifdef CONFIG_KILN_SIM_TIME_ACCEL
#define TIME_ACCEL ((float)CONFIG_KILN_SIM_TIME_ACCEL)
#else
#define TIME_ACCEL 1.0f
#endif

namespace {

kiln_app_t s_app;

/* Persistence is real even in the simulated build: NVS, the log partition and
 * the file store are flash, and QEMU emulates flash.  Only the plant is
 * simulated. */
kiln_port_flash_t    s_flash;
kiln_port_flash_t    s_fs_flash;
kiln_fileslots_t     s_fileslots;
kiln_suplink_t       s_suplink;
kiln_port_supervisor_t s_sup_port;
kiln_port_kvstore_t  s_kv;
kiln_port_clock_t    s_clock;
kiln_port_system_t   s_system;
kiln_logring_t       s_ring;
kiln_port_logstore_t s_logstore;
kiln_port_filestore_t s_fs;

} // namespace

#ifdef CONFIG_KILN_PLANT_SIM
namespace {

kiln_sim_t             s_sim;
kiln_sim_ports_t       s_sim_ports;
kiln_sim_fs_t          s_sim_fs;      /* only if the flash store fails */

} // namespace
#else
namespace {

/* The real-hardware port instances.  Static, because the composition root owns
 * them for the lifetime of the image and kiln_app holds pointers to them. */
kiln_port_tc_t         s_tc_port;
kiln_port_tc_t         s_case_tc_port;
kiln_port_heat_t       s_heat_port;
kiln_port_current_t    s_current_port;
kiln_port_counters_t   s_counters_port;
kiln_port_door_t       s_door_port;
kiln_port_alarm_t      s_alarm_hw_port;
kiln_port_display_t    s_display_port;
kiln_port_input_t      s_input_port;
kiln_port_net_t        s_net_port;

} // namespace
#endif

/* --- port_alarm: a stub, until the buzzer adapter exists ---------------- */

namespace {

kiln_alarm_pattern_t s_alarm = KILN_ALARM_OFF;

void alarm_set(void *ctx, kiln_alarm_pattern_t pattern)
{
    (void)ctx;
    if (pattern != s_alarm) {
        s_alarm = pattern;
        ESP_LOGI(TAG, "alarm: %s",
                 pattern == KILN_ALARM_OFF      ? "off" :
                 pattern == KILN_ALARM_COMPLETE ? "complete" : "FAULT");
    }
}

const kiln_port_alarm_t s_alarm_port = { .ctx = NULL, .set = alarm_set };

/* --- the 10 ms output window (SWA-07) ------------------------------------ */

/* Runs in esp_timer context: allocation-free, lock-free and short, which is
 * exactly what kiln_app_window_tick is written to be. */
void window_timer_cb(void *arg)
{
    (void)arg;
    kiln_app_window_tick(&s_app, WINDOW_PERIOD_MS);
}

/* --- tasks -------------------------------------------------------------- */

/* The safety task is the only writer of heat authority (SWA-04) and the highest
 * priority task in the system (SWR-SAF-13, SWR-NFR-03). */
void safety_task(void *arg)
{
    (void)arg;
    TickType_t next = xTaskGetTickCount();
    const TickType_t period = pdMS_TO_TICKS(SAFETY_PERIOD_MS);

    esp_task_wdt_add(NULL);     /* SWR-SAF-14 */

    for (;;) {
        kiln_app_safety_cycle(&s_app, (float)SAFETY_PERIOD_MS / 1000.0f * TIME_ACCEL);
        esp_task_wdt_reset();
        vTaskDelayUntil(&next, period);
    }
}

void acquire_task(void *arg)
{
    (void)arg;
    TickType_t next = xTaskGetTickCount();
    const TickType_t period = pdMS_TO_TICKS(ACQUIRE_PERIOD_MS);

    for (;;) {
        /* Drain the supervisor link first, so the acquisition cycle reads a
         * reading from this cycle and not the previous one.  Non-blocking:
         * whatever has arrived is taken, and the staleness timer in
         * kiln_core/suplink is what notices when that is nothing.
         *
         * Pumped here, at 4 Hz, because that is SWR-ACQ-03's acquisition rate
         * and the supervisor's 10 Hz report gives 2.5 frames per cycle of
         * margin.  KILN_SUPLINK_STALE_S is sized against this period. */
        uint8_t rx[64];
        size_t  got;
        while ((got = kiln_hal_suplink_read(rx, sizeof(rx))) > 0u) {
            kiln_suplink_feed(&s_suplink, rx, got);
        }
        kiln_suplink_tick(&s_suplink, (float)ACQUIRE_PERIOD_MS / 1000.0f);

        kiln_app_acquire_cycle(&s_app, (float)ACQUIRE_PERIOD_MS / 1000.0f * TIME_ACCEL);
        vTaskDelayUntil(&next, period);
    }
}

void control_task(void *arg)
{
    (void)arg;
    TickType_t next = xTaskGetTickCount();
    const TickType_t period = pdMS_TO_TICKS(CONTROL_PERIOD_MS);

    esp_task_wdt_add(NULL);     /* SWR-SAF-14 */

    for (;;) {
        kiln_app_control_cycle(&s_app, (float)CONTROL_PERIOD_MS / 1000.0f * TIME_ACCEL);
        esp_task_wdt_reset();
        vTaskDelayUntil(&next, period);
    }
}

/* The only task that touches flash (SWR-LOG-14, architecture 6.1).  Core 0, so an
 * erase -- tens of milliseconds -- cannot delay control or safety on core 1. */
void logger_task(void *arg)
{
    (void)arg;
    for (;;) {
        /* A bounded batch, so a backlog is worked off without monopolising the
         * flash for a whole queue's worth of erases. */
        if (kiln_app_log_drain(&s_app, 8) == 0) {
            vTaskDelay(pdMS_TO_TICKS(100));
        } else {
            vTaskDelay(pdMS_TO_TICKS(10));
        }
    }
}

} // namespace

#ifdef CONFIG_KILN_PLANT_SIM

namespace {

/* The plant is "hardware", so it advances on its own clock rather than being
 * stepped by the firmware.  Core 0, so it cannot delay anything on core 1. */
void plant_task(void *arg)
{
    (void)arg;
    TickType_t next = xTaskGetTickCount();
    const TickType_t period = pdMS_TO_TICKS(WINDOW_PERIOD_MS);

    for (;;) {
        kiln_sim_step(&s_sim, (float)WINDOW_PERIOD_MS / 1000.0f * TIME_ACCEL);
        vTaskDelayUntil(&next, period);
    }
}

/* --- console: watch the firing, and inject the faults ------------------- */
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

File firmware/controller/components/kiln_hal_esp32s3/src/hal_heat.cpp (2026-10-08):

/* SPDX-FileCopyrightText: 2026 Bitcrush Testing
 * SPDX-License-Identifier: GPL-3.0-or-later
 *
 * Heat output: two SSR channels and the heat-enable charge pump
 * (SYS-HW-06, SYS-HW-07, SYS-HW-08, SYS-HW-12, SWA-05, SWA-07, SYS-SAF-02, SWR-SAF-27).
 *
 * ===========================================================================
 * READ THIS BEFORE CHANGING enable_refresh()
 * ===========================================================================
 * SWA-05 and SYS-SAF-02 rest entirely on one property: **heat enable is a square
 * wave this function generates, one edge per call, and nothing else.**
 *
 * The pin drives an RC charge pump that holds the contactor coil only while it
 * keeps seeing edges.  Stop calling this -- crash, hang, deadlock, a missed
 * deadline, a panic, a power loss -- and the coil de-energises in about a
 * second with no code involved.  That is the whole of SYS-SAF-02, and it is why
 * SWR-SAF-14's watchdog requirement costs nothing extra: a watchdog expiry removes
 * heat by the same mechanism as any other way of failing to run.
 *
 * Three changes would each leave this file compiling, the board working on the
 * bench, and the property silently gone:
 *
 *   - setting the pin to a level instead of toggling it;
 *   - handing the toggle to LEDC, MCPWM, RMT or any other peripheral that can
 *     keep producing edges after the CPU has stopped executing;
 *   - calling it from a timer callback rather than from the safety task.
 *
 * The third is the subtle one.  An esp_timer callback runs from a dedicated
 * task that a hung *safety* task does not block, so moving the refresh there
 * would keep the contactor closed while the supervisor was dead.  It must be
 * called by the task that is also evaluating the rules, so that the thing
 * holding the contactor closed is the thing deciding whether it should be.
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

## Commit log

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2026-09-29 Add schematic, housing, firmware core, and current-transformer requirements
    Copyright holder is Bitcrush Testing throughout.
    Requirements and architecture
    Add a mandatory current transformer (Stromwandler) on the heater circuit,
    resolving OQ-02. New FR-CUR group (14 requirements) covers true-RMS
    measurement gated to the commanded output state, calibration, reference
    learning and logging. Six new safety rules SR-25..SR-30 detect a defective
    relay electrically rather than inferring it from temperature:
    SR-25 relay fail-on current during a commanded-off window
    SR-26 relay fail-off no current during a commanded-on window
    SR-27 weld discrimination drop the con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
    [kilncontrol.kicad_pcb, kilncontrol.kicad_sch, kilncontrol.scad]
2026-09-29 Replace the external buzzer with an on-board one, shrink the test points
    Buzzer
    J9, the screw terminal for an external buzzer, is replaced by BZ1 on the
    board: a TMB12A05, 5 V active (self-driving) magnetic buzzer, LCSC C96093.
    Active rather than passive: the 5 V-capable SMD passive part found on LCSC
    is rated 2.5-4.5 V and would be overdriven on the 5 V rail, and an active
    buzzer drops straight into the existing Q4 low-side driver and its flyback
    diode. No circuit change and no firmware change, because SR-20 asks the
    fault and completion alarms to be distinguishable by pattern, not by pitch,
    which kiln_alarm_pattern_t already does.
    This removes the auxiliary-relay output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
    [kilncontrol.kicad_pcb, kilncontrol.kicad_sch, kilncontrol.scad]
2026-10-04 ports: add the missing hardware interfaces
    The port layer covered sensing, output and storage but not the heater
    current that SR-25..SR-30 are written against, so the current rules could
    not be expressed at all. Adds:
    port_current gated burst acquisition (FR-CUR-01..05, FR-CUR-11). Hands
    over raw ADC counts rather than amps: FR-CUR-11 separates
    an absent transformer from a genuine zero by the absence
    of any signal including noise, and an adapter that
    helpfully squelched small values would destroy that.
    port_counters persisted switching-operation counts (FR-CUR-13). Separate
    from port_kvstore b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
2026-10-04 core: implement the heater-current subsystem and SR-25..SR-30
    Requirements 5.2 makes the current rules the primary detection of relay and
    element failure, with the thermal rules as backstop. None of it existed:
    the fault codes 21-26 and warnings 109-112 were allocated and the operator
    text was written, but no rule anywhere could raise them. Architecture
    milestone M4b.
    core/current measures and scales; it does not decide. Gating is the whole
    point -- a time-proportional output at 2 % duty is off 98 % of the time, so
    a blind average reads 2 % of full current and says nothing about the relay.
    Measuring inside a commanded window turns the reading into a statement
    about the relay instead, which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
2026-10-04 core: fix correctness, timing and contract defects in the existing logic
    pid, window, tempfilt, setpoint, profile, autotune, logrec.
    Timing and cost:
    setpoint's time prediction copied the whole generator (~440 bytes,
    including an embedded program) onto the caller's stack and ticked it up
    to 720 000 times. These are display and API calls served from the HMI and
    web tasks, against NFR-02's 50 ms ceiling. The arithmetic is closed form,
    so it is now computed directly; the forward simulation survives as the
    test oracle, which keeps the agreement without paying for it. It turns
    out the closed form is the more accurate of the two -- the simulation
    adds rate/3600 to a float tens of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
2026-10-04 sim: plant simulator with heater current and electrical fault injection
    First-order-plus-dead-time for temperature per ASM-01, with configurable
    gain, time constant, dead time, ambient, high-temperature radiative loss
    and seeded noise (TR-11, TR-12).
    The part that matters for the current rules is that one plant drives both
    channels. Heat and current come from the same series chain -- contactor,
    SSR, elements -- so an injected element failure shows up in degrees and in
    amps exactly as it would on a real kiln, and the thermal and electrical
    rules can be driven by the same scenario rather than by two models that
    have to be kept in agreement (TR-27).
    Synthesises CT bursts as a sine about the m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
2026-10-04 build: ESP-IDF project root, runnable under QEMU against the simulated kiln
    The project root, partition table and composition root, none of which
    existed -- kiln_ports/CMakeLists.txt was the only build file in the
    repository.
    partitions.csv realises architecture 10.1: a 2 MB OTA pair for NFR-13,
    NVS, LittleFS, and kilnlog as a custom data partition rather than a
    filesystem, because AD-08 wants a raw ring of fixed records whose wear
    pattern is provable.
    sdkconfig.defaults pins what a default could otherwise change under us:
    the task and interrupt watchdogs of SR-14, brownout detection for SR-15, a
    panic that reboots rather than sitting at a prompt with the heaters in
    whatever state they wer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
    [partitions.csv]
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2026-10-04 build: a hardware time constant does not accelerate with the plant
    Two defects found by running the real image end to end, both of which would
    have latched a fault within seconds of starting a firing.
    AD-05's charge pump is hardware with a real 1 s time constant. The
    simulator integrates in accelerated seconds, so under
    CONFIG_KILN_SIM_TIME_ACCEL the decay expired between two safety refreshes
    100 ms apart and dropped the contactor continuously -- which then reads,
    entirely correctly, as no heater current and latches SR-26. Scaled at the
    composition root, where the acceleration is chosen. The general rule, for
    anything else added to the simulator: a time constant belonging to the
    hardware do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
2026-10-04 core: the circular sample log, as logic a host test can cut power on
    AD-08's ring was to live inside the log-store adapter (architecture 5.2).
    It is in kiln_core/logring over a new port_flash instead, and that is a
    deliberate revision -- recorded as AD-19.
    Everything interesting about the ring is a decision with a failure mode the
    requirements name explicitly: head discovery across 512 sector headers,
    erase-immediately-before-write ordering so that a power cut cannot destroy
    records the index still claims exist, and terminating a sector scan at a
    torn record (FR-LOG-06, FR-LOG-08). Behind esp_partition none of it can be
    tested. Over a port_flash it is driven by a fake that enforces NOR
    sema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
2026-10-04 hal: esp32s3 adapters for storage and system, and the host fakes beside them
    Now buildable and built: ESP-IDF 6.0.1, esp32s3, no warnings, 236 kB image
    with 89 % of the OTA slot free (NFR-13).
    kiln_hal_esp32s3 carries the adapters that have no logic left in them, which
    is the shape every adapter should have: the log partition over
    esp_partition (three pass-through calls, because AD-19 put the ring in the
    core), NVS as a blob store (because configmodel owns the schema), the
    monotonic and wall clocks kept separate as FR-NET-08 requires, and the reset
    cause, firmware identity and task watchdog of NFR-15, SR-14 and FR-UPD-06.
    The reset-cause mapping lives in the adapter so that kiln_core/runst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
2026-10-06 feat: door interlock, read-only web, three-phase metering, German
    Four things, plus the security concept the safety work implied.
    SR-31, the door interlock. Two tiers, which is the part worth not losing in
    a later refactor. Heat comes off and the contactor drops on the *first* open
    sample, with no timer at all, because that is what "immediately" has to mean
    for a door. Only the latch waits for door_confirm_s (200 ms), so one sample
    spoiled by the switching noise of a multi-kilowatt load costs a fraction of a
    second of duty instead of stopping a healthy firing (HZ-10). A latch-only test
    would pass against an implementation that waited 200 ms before dropping the
    heater, so the tiers are teste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
    [main.cpp]
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2026-10-06 feat: the firmware runs on real hardware, and single-phase only
    Three things that happened in sequence, and the last one undoes part of the
    middle one, which the tasklist records rather than hides.
    TARGET ADAPTERS (M2, M4b). Before this the esp32s3 image bound the simulator
    and #error'd without it. There is now a second configuration that binds the
    board, and both build with zero warnings. Port coverage goes from 4 of 16 to
    12: MAX31856 over SPI, the SSR channels and the charge pump, the CT on ADC1
    through the DMA continuous driver, the lid sense, the buzzer with SR-20's two
    patterns, the NVS switching counters, the SSD1306, and the encoder on the
    pulse counter unit. board_pins.h is the sin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
    [board_pins.h, hal_current.cpp]
2026-10-06 feat: WiFi, the HTTP transport, and a web interface that only reads
    Two adapters and a decision, the last of which reshaped the interface.
    WiFi (FR-NET). Station with access-point fallback, exponential-backoff
    reconnection, SNTP and the diagnostics of FR-NET-09. Thirteen of sixteen ports
    now have a target adapter.
    FR-NET-07 shaped the file: losing the network must not interrupt, pause or
    otherwise alter a running firing. So nothing blocks, nothing sits on the
    control path, and the radio is started *after* kiln_app_init, with the kiln
    already fully operational before it is touched. Reconnection is event-driven
    with a 1 s to 60 s backoff, because an adapter that retried in a tight loop
    would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
    [hal_net.cpp, main.cpp]
2026-10-06 lang: ten more clang-tidy checks gating, and four real defects
    Works through tasklist F1b and F2 to F8, and drops F10. Every check these
    items deferred is now enabled with no suppressions baseline, and the counts
    they carried were mostly wrong because they had been measured against the host
    compile database alone -- which is the same gap F1b was really about.
    THE DEFECTS. Four, and the MAX31856 decode is the one that matters. The
    linearised hot junction was assembled as ((int32_t)r[2] << 24) | ..., and
    r[2] << 24 overflows int32_t -- undefined behaviour -- for exactly the byte
    that means "below zero". It is built in uint32_t and converted now. The two
    deliberate *arithmetic* right shifts be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
    [partitions.csv]
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2026-10-07 feat: the supervisor's project, part and link protocol
    STM32G031K8T6, a project that builds for it, and the wire format defined once
    for both ends. Settles R6's part choice and the protocol half of R8.
    THE PART. The family was decided by one property: the G0's independent
    watchdog is clocked from the LSI rather than the system clock, so a stopped or
    wrong clock does not stop the watchdog, and once started it cannot be disabled
    in software. A supervisor whose watchdog shares a fate with its clock is not a
    supervisor. LQFP32 rather than QFN so every pin can be probed and the part can
    be reworked, for the same reason HR-19 already wants top-side test points.
    64 KB against a firmware that uses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
    [main.cpp, pins.h, startup.cpp]
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2026-10-07 feat: one chamber couple, and a button that clears the latch
    Settles R3 and R4.
    ONE COUPLE, THE SUPERVISOR'S, RELAYED OVER THE LINK. The option of giving the
    supervisor a second chamber couple is declined: it would mean a second
    penetration, a second probe to fit correctly and a second thing to get wrong in
    the field, and one well-fitted couple reporting to a supervisor that cannot be
    talked out of tripping is the simpler product.
    Two consequences are now written down rather than left to be discovered.
    The ESP32 no longer has any independent view of temperature. SR-05, SR-06,
    SR-07 and SR-08 all reason about a value that arrived over the link. They still
    work, and the fault bits arrive wi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
    [main.cpp]
2026-10-07 feat: the lid leaves the supervisor; it is already safe in hardware
    The lid switch breaks the contactor coil in hardware (HR-21), so it is safe
    with no firmware involved at all, and SR-31's latch is gated on "while a
    heating state is active", which only the ESP32 knows. The supervisor's lid
    rule was therefore a third path that duplicated the hardware one and added a
    failure mode of its own: it latched on lid open unconditionally, so it would
    have tripped every time the kiln was loaded cold, and HZ-10 names nuisance
    trips as how protections come to be disabled. Removed.
    The lid sense goes to the ESP32, which already has it: KILN_PIN_LID_SENSE and
    hal_io.cpp's port_door adapter are unchanged,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
    [main.cpp, pins.h]
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2026-10-07 feat: the ESP32 reads the chamber temperature from the supervisor
    Supervisor TX on IO47. The chamber thermocouple is the supervisor's now, so
    this is the ESP32 side of AD-22.
    NOTHING IN THE CORE CHANGED. The frames are bound as a kiln_port_tc_t, so the
    control and safety paths still read a thermocouple port and only the thing
    behind the port moved. A link that never comes up, or goes quiet, reports
    KILN_TC_FAULT_COMMS and returns an error, which is exactly what the MAX31856
    adapter does when the part does not answer, so SR-04's existing grace and latch
    handle a dead supervisor with no new rule and no special case. From the core's
    point of view the front end stopped answering, which is true.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
    [board_pins.h, hal_suplink.cpp, main.cpp]
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2026-10-08 feat: RAM, stack and program-sequence diagnostics on the supervisor
    The three remaining code-level measures from the certification gap analysis,
    plus the rule that decides what a failed diagnostic means.
    SWR-SAF-33, working memory. A pattern test driving every bit of every tested
    word to both states, then an ADDRESS-DEPENDENT pattern. The second is required
    rather than decorative: two words that alias because an address line is stuck
    pass every uniform pattern, since both hold the same value and both read back
    what was written, and fail only when asked to hold two different values at once.
    The whole free region is tested before heat can be permitted, then walked 64
    bytes a cycle. The regio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
    [main.cpp, selfcheck.h]
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2026-10-08 feat: the bed-of-nails fixture, from the board, via pinside
    docs/test-concept.md asks for a HIL fixture and safety.md section 10 still lists
    the central claim of the design, that the contactor releases when the safety task
    stops, as not yet performed. Nothing in this repository can perform it without a
    jig. This is the jig, generated from the board itself rather than measured off it.
    fixture/kilncontrol-fixture.json is the source; board/ and firmware/ are
    generated from it and are regenerated rather than edited. pinside derives
    footprint UUIDs from the config rather than randomising them, so an unchanged
    config produces a byte-identical project and a real change diffs as only itself.
    The fi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
    [kilncontrol-fixture.kicad_pcb, kilncontrol-fixture.kicad_sch]
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2026-10-09 chore: the kicad project is safekiln, and the fixture follows it
    The board, schematic and project file are renamed from kilncontrol to
    safekiln, matching what the firmware, the image and the documentation have
    called this product since the repository was reorganised.
    Three references had to move with it, and they are the ones that would have
    failed silently rather than loudly:
    fixture/pinside-baseline.json names the board it is a baseline OF, so a
    rename without it means `pinside check` has nothing to compare against.
    fixture/kilncontrol-fixture.json carries an absolute path to the board. It
    keeps its own filename: that is the fixture's name, not the project's, and
    renaming an i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
    [kilncontrol.kicad_pcb, safekiln.kicad_pcb, safekiln.kicad_sch]
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2026-10-09 feat: no provisioning AP, and wifi is set up at the kiln instead
    The access point is removed rather than regulated. It came up whenever the
    station could not join, served a page whose entire purpose was to accept
    credentials, and could start open because nothing required net.ap_pass to be
    set. That was TH-11, SRR-08 and OQ-S4, and OQ-S4 was the only item on the
    Cyber Resilience Act list that was a live weakness in code that existed rather
    than something unbuilt or on paper.
    A rule about a surface is worth less than not having the surface. SWR-NET-02
    and SWR-NET-05 are withdrawn, SWR-NET-11 and SWR-NET-12 replace them, and the
    device now has exactly one radio role: station. net.ap_ssid, net.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
    [hal_net.cpp, main.cpp]
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2026-10-09 fix: the qemu job had no qemu, and the analysis job had two real findings
    THE QEMU SMOKE TEST WAS NEVER RUNNING QEMU. The instrumentation added two
    commits ago answered it on the first run:
    --- qemu: NOT ON PATH ---
    qemu-system-xtensa: command not found
    --- idf.py qemu exited 127 after 71 bytes ---
    Exit 127, and `|| true` had been swallowing it since the job was written. The
    log was not truncated, not buffered and not killed too early, which were the
    three theories; there was no emulator. `idf_tools.py install qemu-xtensa`
    installs it and `export.sh` does not put it on PATH in this image, so the step
    now finds the binary itself and fails loudly if the install produced none,
    rat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
    [hal_net.cpp, hal_prod.cpp]
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2026-10-09 fix: a NOLINTNEXTLINE has to be on the line before the declaration
    Converting SUP_RAM_PATTERNS' comment into a doxygen block put a second comment
    between the suppression and the declaration, so bugprone-dynamic-static-
    initializers fired again and the clang-tidy job went red. The suppression is
    back on the block's own closing line, which is where the original had it and
    the only place it works.
    The documentation is unchanged at 76 of 76, and the two gates disagreeing about
    the same line is a fair description of what a comment has to satisfy here.
    [selfcheck.h]
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2026-10-09 docs: the two diagrams a safety function is actually read for
    The unit design now draws its own state machine and its own program-sequence
    graph, from \dot blocks in the headers beside the code they describe. Being in
    the source is the point: a picture in another document drifts from the code and
    the drift is found by whoever is auditing.
    THE TRIP LOGIC'S STATE MACHINE, on sup_step. Four states rather than the two
    the ASCII sketch had: WAITING does not latch, because "the sensor never got
    going" and "the sensor was working and stopped" are different and only the
    second is a fault for an operator to acknowledge; and REVOKED is reachable from
    either working state and has no edge out of it wit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
    [selfcheck.h]
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2026-10-10 fix: the configuration that ships did not compile, and nothing was building it
    Checking tasklist O and P found something larger than any item in them. Every
    CI job builds sdkconfig.qemu, which sets CONFIG_KILN_PLANT_SIM and compiles the
    WiFi, the HTTP server and the whole hardware path out of main.cpp. The
    configuration that will actually ship was therefore guarded by no build at all,
    and O3 claimed "it compiles and passes analysis" on that basis.
    Built for the first time today. It did not compile: two -Wformat-truncation
    errors, one in the version string that has been there far longer than the WiFi
    work and one mine from the network scan. Both are bounded explicitly now, which
    is the same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
    [main.cpp]
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2026-10-10 feat: kiln.local, by way of one dependency with conditions on it
    SWR-NET-04 has been open since mDNS left the ESP-IDF tree for the component
    registry. The options were vendoring several thousand lines of somebody
    else's protocol implementation, dropping the requirement, or taking the
    dependency; UR-CON-04 forbade the third only insofar as it forbade an
    unpinned fetch, so it is reworded to say what makes a fetched component
    auditable rather than to forbid fetching:
    1. pinned exactly, never to a range,
    2. the resolved dependencies.lock committed, so what a release was built
    from is recoverable from the repository alone,
    3. present in the SBOM with its licence.
    Web assets stay vend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
    [hal_net.cpp]
2026-10-10 feat: the file store proves its writes, and retires what cannot hold them
    Q1 was recorded as an accepted trade and the trade was made against the
    wrong failure mode. A NOR sector at the end of its life does not report an
    error: it takes the write, returns success, and holds something else. The
    store's answer was the CRC on the next read, which on this device is after a
    firing rather than during the write it could still have redirected.
    Every write is now read back and re-validated through read_copy, the same
    path a mount uses, before the in-RAM index points at it. A copy that does
    not verify retires its region and the write is re-attempted in a free region
    at a higher seq, up to KILN_FILESL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
    [main.cpp]
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2026-10-10 feat: the buzzer says "finished" briefly and "something is wrong" relentlessly
    The firing-finished sound was fifteen repetitions of a chirp over thirty
    seconds, and the fault sound was a 200/200 ms beat that is more polite than
    the situation deserves. Both are rewritten:
    completion three 90 ms chirps, then five seconds of quiet. A firing that
    took nine hours has finished correctly: that is good news and
    wants a notification, not an alarm. hmi.alarm_duration_s
    defaults to 4 s rather than 30, so the operator hears the burst
    once; the 0 to 600 s range is unchanged for anyone who wants
    the kiln to keep saying so until some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
    [hal_io.cpp]
2026-10-10 feat: the display speaks German, and says why a join failed
    Three things O4 was waiting on, none of which needs hardware.
    **The frame was English.** kiln_core/faults has carried faults and warnings
    in both languages from the start, so a device set to German announced its
    faults in German inside an English frame: every screen title, the whole menu,
    both answers to a confirmation and every footer were string literals at their
    draw sites. SWR-NFR-23's "no text embedded at its point of use" was half
    true, and is now true: 46 strings in kiln_hmi/strings, in two languages, and
    no operator-facing literal left in hmi.cpp.
    The German uses the transliteration kiln_core/faults has always used, becaus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
    [hal_net.cpp, main.cpp]
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2026-10-10 refactor: the programs are firmware, so the program store goes
    P3, finished the way the pre-compiled-profiles decision implied. SWR-PRG-04
    asked for 20 program slots in non-volatile storage, and with SWR-PRG-07,
    SWR-PRG-08 and SWR-PRG-10 withdrawn there was nothing on the device that
    could create or edit one: the store held a copy of the three examples that
    arrive in the image and nothing else. Persistence of something already
    persistent, in a medium that wears out, behind a seeding path that could fail
    on a first boot and a store that could fail to mount.
    It is withdrawn, program_store is deleted, and the API, the HMI and the
    development harness all read kiln_profile_example.
    What that fi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
    [main.cpp]
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

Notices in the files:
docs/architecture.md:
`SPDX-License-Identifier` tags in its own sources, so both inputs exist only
